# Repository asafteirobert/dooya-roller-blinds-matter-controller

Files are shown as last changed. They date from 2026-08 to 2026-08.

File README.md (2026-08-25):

# Roller Blinds Matter Controller

A Matter over Wi-Fi device for controlling generic Dooya wireless roller blinds. Compatible with blinds that use the Dooya non-rolling code protocol over 433MHz. They are sold under many generic brands such as Smart Home, glb, MOSEL, and HEICKO, have model names such as DM35R, and use remotes such as DC104, DC105, DC169.

## Features
- Position control based on timing. The device times the up/down/stop commands based on total travel time to move the blind to the desired position. At the top and bottom position the stop command is not sent and any accumulated error is fixed.
- Ability to add multiple blinds to the same device.
- Configure the number of blinds and blind parameters (rise time, lower time, channel and remote code) through Matter using a custom script.
- Device listens to the physical remote for commands to keep the internal and Matter state in sync regardless of whether the blinds are controlled through Matter or through the physical remote.

## Hardware
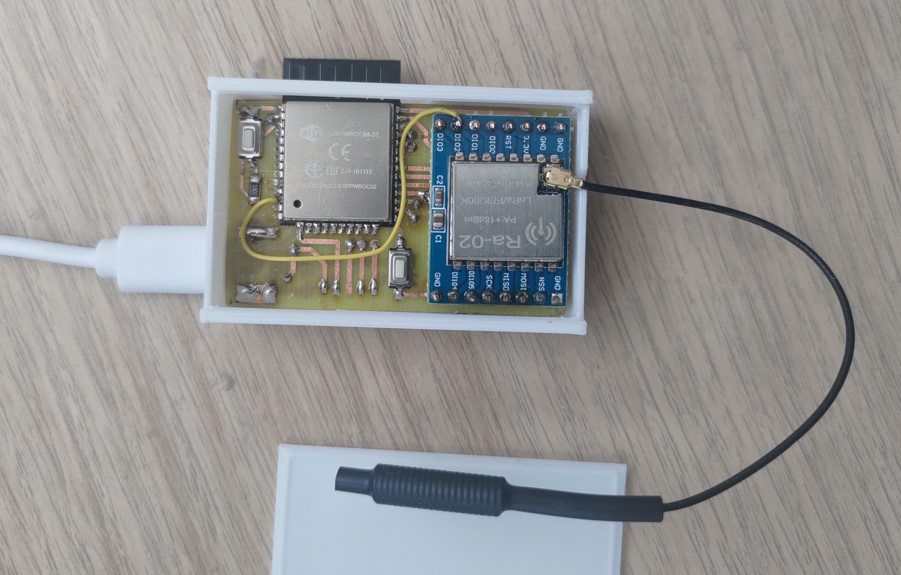
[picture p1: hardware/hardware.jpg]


ESP32 (ESP-WROOM-32) connected to an SX1278 RF module. The RF module both transmits the OOK commands the wireless remote would send and receives commands from the physical remote, so the device can stay in sync regardless of how the blind was last controlled.

See [hardware](hardware/).

## Commissioning

Use the scripts in `mfg-tool-scripts/` to generate and flash per-device commissioning data:

```bash
./0_clean.sh      # remove previous outputs
./1_generate.sh   # generate new commissioning data
./2_flash.sh      # flash to device (default port: /dev/ttyUSB0)
```

Override the port: `PORT=/dev/ttyACM0 ./2_flash.sh`.

Commissioning QR code (alongside the manual code) can be found in `mfg-tool-scripts/out/fff1_8003/<hash>/<hash>-qrcode.png`.

## Obtaining your unique remote ID code

Enable debug logging by uncommenting and commenting out the relevant lines in `sdkconfig.defaults` and look for `Received remote command X from remote 0xXXXXX channel X`. Use the script in `tools/write-blind-config` to write the remote ID and channel to the correct Matter endpoint (see below).

Alternatively, you can use an RTL-SDR dongle and the [rtl_433 tool](https://github.com/merbanan/rtl_433) tool with the `dooya_curtain.conf` file in this repository: `rtl_433.exe -c hardware/dooya_curtain.conf`.

## Configuring blinds (tools/write-blind-config)

`matter-server` and `@matter/nodejs-shell` can't write the device's custom manufacturer clusters (`BlindConfig` / `SystemConfig`), so this standalone matter.js script commissions itself as a second controller on the device (Matter supports multiple admins, so this doesn't disturb an existing Home Assistant pairing) and writes the attributes directly.

**Setup** (from `tools/write-blind-config/`):
```bash
npm install
```

**Usage:**

Comission the device in this script using the pairing code, then set the number of blinds, then configure each blind.
```bash
node write-blind-config.mjs [--pairing-code <code>] [--endpoint <n>] [--lower <ms>] [--rise <ms>] [--channel <n>] [--remote-id <hex-or-decimal>] [--num-blinds <n>]
```
- `--pairing-code`. The script needs to commission itself onto the device, which requires a pairing code from Home Assistant (device page → "..." menu → "Share device"). After that, the script's local storage remembers the pairing, so `--pairing-code` can be omitted on later runs.
- `--lower` sets the time in milliseconds it takes for the blind to go from fully open to fully closed.
- `--rise` sets the time in milliseconds it takes for the blind to go from fully closed to fully open.
- `--remote-id` sets the unique remote pairing code
- `--num-blinds` always targets endpoint 0 and reboots the device ~2s after the write to rebuild its set of blind endpoints. If combined with per-blind flags, those are written first.
- Any subset of `--lower`/`--rise`/`--channel`/`--remote-id`/`--num-blinds` is fine, as long as at least one is given.
- `--endpoint` selects which blind's config the first four flags target (default `1`). I can be found in the Matter Server web ui in Home Assistant. Or from the device serial log: `Window covering N created with endpoint_id X`.

Example — configure blind on endpoint 2 with a 12s lower time, 13s rise time, channel 2, remote ID `0x123456`:
```bash
node write-blind-config.mjs --endpoint 2 --lower 12000 --rise 13000 --channel 2 --remote-id 0x123456
```
## AI Disclaimer
This project was coded with heavy use of Claude Code

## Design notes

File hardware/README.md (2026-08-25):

# Hardware

- **[Schematic](Schematic/)** — Schematic, PCB and EasyEDA project. The PCB was manufactured at home with only the top side, so some connections use wires. This is why some of the routing, large vias and DRC rules look strange.
- **[3d print](3d%20print/)** — 3D model of the case.

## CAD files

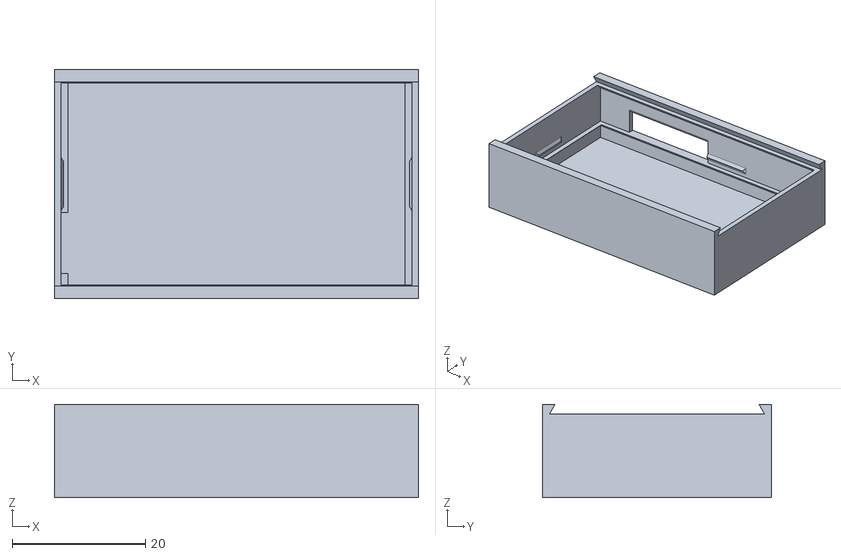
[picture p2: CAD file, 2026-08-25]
hardware/3d print/Roller blinds Case.stl
54.7 x 34.4 x 14.1

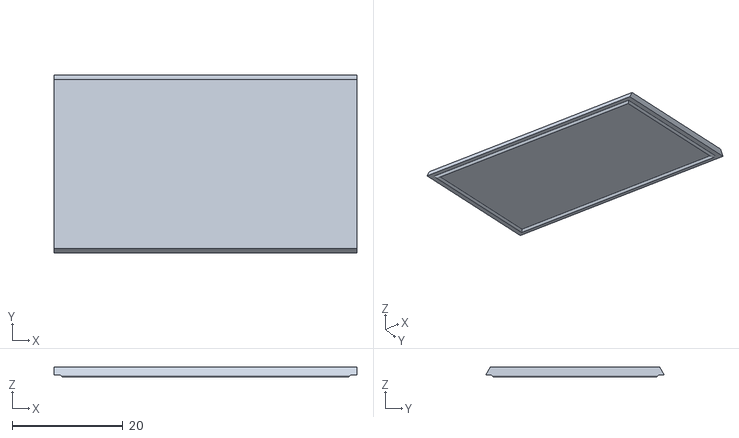
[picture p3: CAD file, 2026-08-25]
hardware/3d print/Roller blinds Case Lid.stl
54.7 x 32.2 x 1.80

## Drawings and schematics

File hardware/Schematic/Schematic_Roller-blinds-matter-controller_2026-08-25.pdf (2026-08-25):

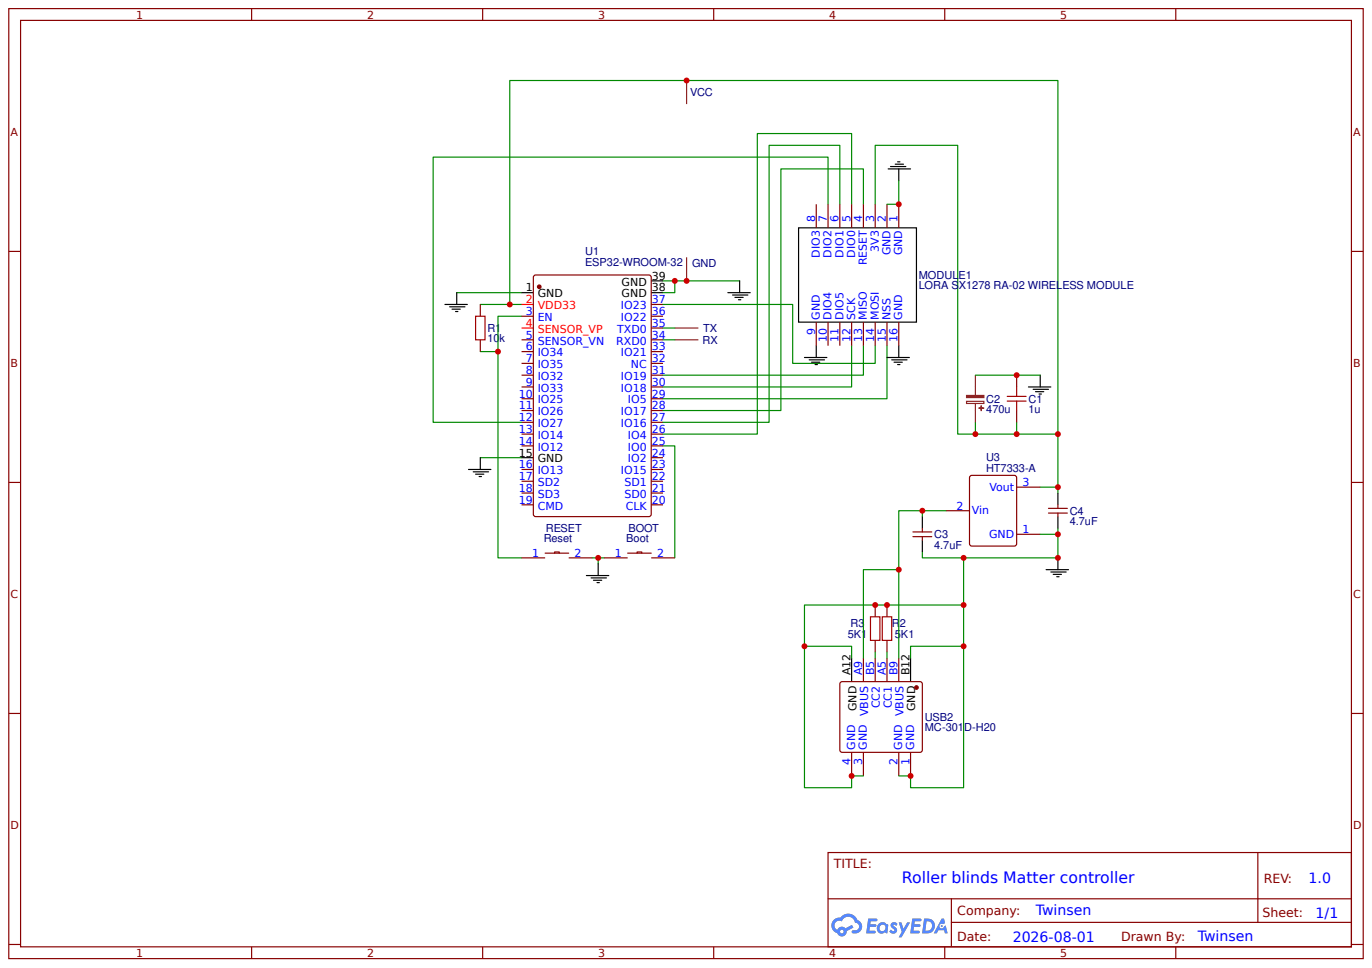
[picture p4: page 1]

GND 1 GND 2 3V3 3 RESET 4 DIO0 5 DIO1 6 DIO2 7 DIO3 8 GND 9 DIO4 10 DIO5 11 SCK 12 MISO 13 MOSI 14 NSS 15 GND 16

MODULE1
LORA SX1278 RA-02 WIRELESS MODULE

CLK 20 CMD 19 SD3 18 SD2 17 IO13 16 GND 15 IO12 14 IO14 13 IO27 12 IO26 11 IO25 10 IO33 9 IO32 8 IO35 7 IO34 6 SENSOR_VN 5 SENSOR_VP 4 EN 3 VDD33 2 GND 1

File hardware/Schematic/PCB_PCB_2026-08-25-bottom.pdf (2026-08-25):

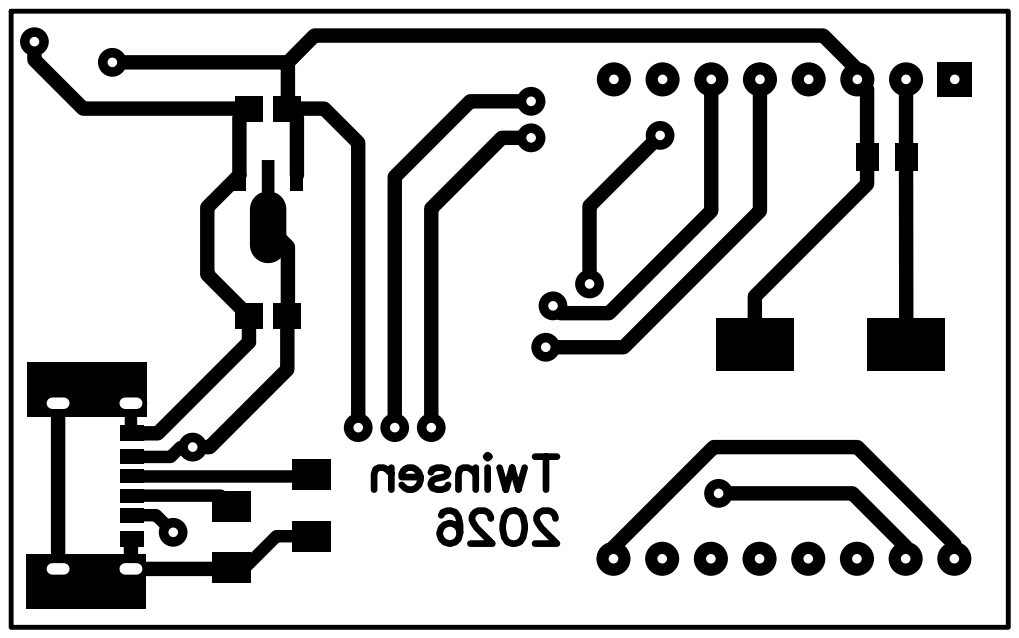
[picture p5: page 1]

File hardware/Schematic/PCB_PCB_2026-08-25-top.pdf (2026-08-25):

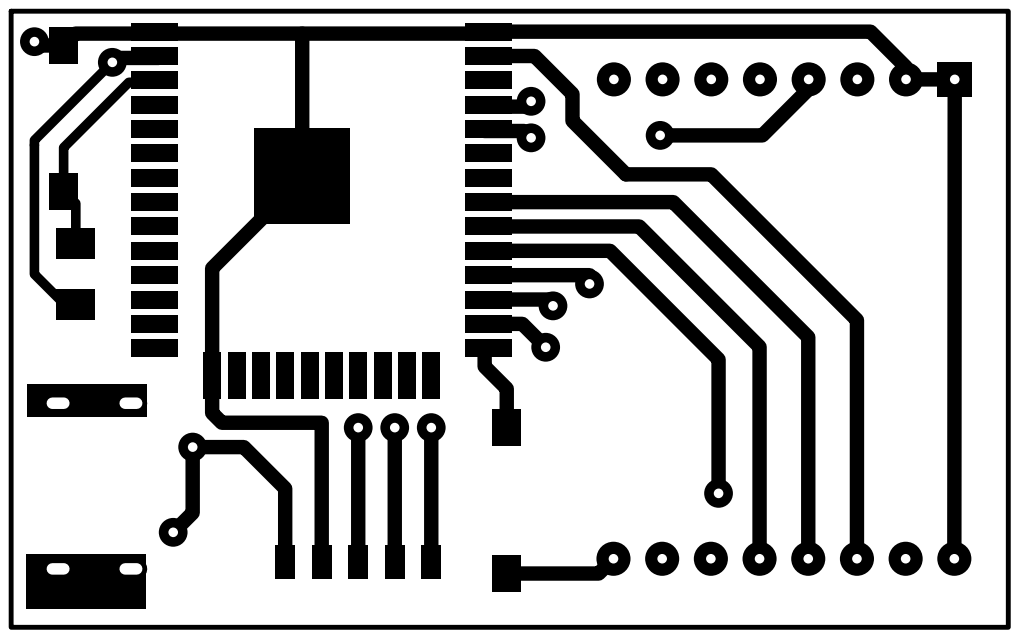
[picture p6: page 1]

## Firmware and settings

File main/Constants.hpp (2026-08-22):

#pragma once
#include <cstdint>

#include "driver/gpio.h"

/** Factory-reset button (active-LOW, internal pull-up) */
#define BOARD_BUTTON_GPIO GPIO_NUM_0

#define SX1278_NSS_GPIO GPIO_NUM_5
#define SX1278_RESET_GPIO GPIO_NUM_17
#define SX1278_DIO0_GPIO GPIO_NUM_4
#define SX1278_DIO1_GPIO GPIO_NUM_16
// Raw OOK "Data" output (continuous mode), used to receive commands sent by the physical remote.
// Only meaningful while the chip is in receive mode; see SX1278Driver's RX decode state machine.
#define SX1278_DIO2_GPIO GPIO_NUM_27

// Debug-only outputs
#define SX1278_RX_DEBUG_1_GPIO GPIO_NUM_25 
#define SX1278_RX_DEBUG_2_GPIO GPIO_NUM_26

// Maximum number of blinds this firmware can be configured to control. Shared between app_main
// (which sizes its per-blind endpoint/controller arrays with it) and RadioController (which
// sizes its remote-command routing table with it), so the two stay in sync.
constexpr uint8_t MAX_BLINDS = 8;

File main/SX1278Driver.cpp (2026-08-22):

#include "SX1278Driver.hpp"
#include "Constants.hpp"

#include <algorithm>
#include <cinttypes>
#include <utility>

#include <driver/gpio.h>
#include <driver/mcpwm_cap.h>
#include <driver/pulse_cnt.h>
#include <driver/spi_master.h>
#include <esp_attr.h>
#include <esp_log.h>
#include <esp_rom_sys.h>
#include <esp_timer.h>
#include <freertos/FreeRTOS.h>
#include <freertos/semphr.h>
#include <freertos/task.h>

namespace
{
// --- OOK/PWM timing
constexpr uint32_t SYNC_US = 4600;
constexpr uint32_t SHORT_US = 350; // logical bit 0
constexpr uint32_t LONG_US = 700;  // logical bit 1
constexpr uint32_t RESET_US = 7500; // silence between repeated frames

// On-air sample period. Must evenly divide every timing value above (it's the GCD: 50 = 2*5^2).
constexpr uint32_t SAMPLE_US = 50;
static_assert(SYNC_US % SAMPLE_US == 0 && SHORT_US % SAMPLE_US == 0 && LONG_US % SAMPLE_US == 0,
              "SAMPLE_US must evenly divide the pulse widths or the waveform will be built with rounding error");

constexpr uint32_t SYNC_CHIPS = SYNC_US / SAMPLE_US;
constexpr uint32_t SHORT_CHIPS = SHORT_US / SAMPLE_US;
constexpr uint32_t LONG_CHIPS = LONG_US / SAMPLE_US;

constexpr double FXOSC_HZ = 32000000.0;
constexpr double RF_FREQUENCY_HZ = 433915000.0; // Dooya remotes operate in the 433 MHz ISM band
constexpr uint32_t BIT_RATE_BPS = 1000000 / SAMPLE_US; // one on-air bit == one SAMPLE_US chip

constexpr int SPI_CLOCK_HZ = 4 * 1000 * 1000; // conservative for hobby-wired breakout boards

// The FIFO is only 64 bytes deep, so any payload longer than that (ours always is) is streamed in
// while transmitting per the datasheet's "Handling Large Packets" procedure: pre-fill, enable Tx,
// then top up in FIFO_CHUNK bursts whenever FifoLevel (mirrored on DIO1) drops to the threshold.
constexpr size_t FIFO_CAPACITY = 64;
constexpr size_t FIFO_CHUNK = 32;
constexpr uint8_t FIFO_THRESHOLD = FIFO_CAPACITY - FIFO_CHUNK; // leaves exactly one chunk of headroom

constexpr int64_t FIFO_WAIT_TIMEOUT_US = 500000; // generous vs. the ~60-90 ms a real transfer takes

// Deep enough to absorb a burst of UI/Matter-driven commands without send() ever blocking on air time.
constexpr UBaseType_t COMMAND_QUEUE_LENGTH = 16;
constexpr uint32_t SENDER_TASK_STACK_WORDS = 4096;
constexpr UBaseType_t SENDER_TASK_PRIORITY = 5;

// Minimum gap between the end of one queued command and the start of the next
constexpr uint32_t COMMAND_GAP_MS = 200;

// Deep enough to absorb a burst of repeated button presses without the ISR ever blocking/dropping.
constexpr UBaseType_t RX_FRAME_QUEUE_LENGTH = 8;
constexpr uint32_t RECEIVER_TASK_STACK_WORDS = 4096;
constexpr UBaseType_t RECEIVER_TASK_PRIORITY = 5;

// dio2SetupTask() runs the MCPWM/PCNT setup from core 1 (see there) so their interrupts bind away
// from WiFi/BLE's dispatch, which is pinned to core 0.
constexpr uint32_t DIO2_SETUP_TASK_STACK_WORDS = 3072;
constexpr UBaseType_t DIO2_SETUP_TASK_PRIORITY = 5;
constexpr BaseType_t DIO2_SETUP_CORE = 1;

struct Dio2SetupContext
{
    SX1278Driver* driver;
    SemaphoreHandle_t doneSemaphore;
};

// ESP32's PCNT counter register is a signed 16-bit field.
constexpr int PCNT_LOW_LIMIT = -32768;
constexpr int PCNT_HIGH_LIMIT = 32767;
// handleReceivedEdge() resets rxIsrEdgeCount (and the PCNT counter) back to 0 once it reaches this,
// well below the hardware ceiling above -- see there. Any value comfortably below the ceiling works.
constexpr int PCNT_RESET_THRESHOLD = 20000;

// --- OOK/PWM RX decode tolerances, mirroring buildWaveform()'s encoding in reverse. Only each
// HIGH ("mark") run's duration is decoded -- LONG_US means 1, SHORT_US means 0 -- since the
// complementary space carries no extra information. Each band is separated from its neighbours by
// a dead zone: a duration landing in a gap aborts the in-progress frame (see handleReceivedEdge)
// instead of being forced into the nearest band, so jitter can't silently flip a bit into a
// plausible-but-wrong frame. A dropped frame is harmless -- the remote repeats every press.
constexpr int64_t RX_SHORT_MIN_US = 180;
constexpr int64_t RX_SHORT_MAX_US = 460; // SHORT_US(350) + ~31%
constexpr int64_t RX_LONG_MIN_US = 590;  // LONG_US(700) - ~16% -- 130us dead zone vs RX_SHORT_MAX_US
constexpr int64_t RX_LONG_MAX_US = 1000; // LONG_US(700) + ~43%, comfortably below RX_SYNC_MIN_US
constexpr int64_t RX_SYNC_MIN_US = 2800; // SYNC_US(4600) - ~39%, comfortably above RX_LONG_MAX_US
constexpr int64_t RX_SYNC_MAX_US = 6200; // SYNC_US(4600) + ~35%
constexpr uint8_t RX_FRAME_BITS = 40;

// Below RX_SHORT_MIN_US by a wide margin, so a run this brief is always an RF/electrical glitch,
// never a real mark or space -- see rxPendingValid.
constexpr int64_t RX_NOISE_MAX_US = 50;

// The sync mark is always followed by a fixed 2*LONG_US (1400us) low gap before the first bit's
// mark (see buildWaveform()). Requiring that gap to also match before committing to "in frame"
// needs a noise glitch to land in *two* independent windows to be mistaken for a real frame.
constexpr int64_t RX_POST_SYNC_GAP_MIN_US = 1050;
constexpr int64_t RX_POST_SYNC_GAP_MAX_US = 1850;

// --- SX1278 FSK/OOK register map (see RFM9x/SX1278 datasheet section 6.2) ---
constexpr uint8_t REG_FIFO = 0x00;
constexpr uint8_t REG_OP_MODE = 0x01;
constexpr uint8_t REG_BITRATE_MSB = 0x02;
constexpr uint8_t REG_BITRATE_LSB = 0x03;
constexpr uint8_t REG_FRF_MSB = 0x06;
constexpr uint8_t REG_FRF_MID = 0x07;
constexpr uint8_t REG_FRF_LSB = 0x08;
constexpr uint8_t REG_PA_CONFIG = 0x09;
constexpr uint8_t REG_PA_RAMP = 0x0A;
constexpr uint8_t REG_RX_CONFIG = 0x0D;
constexpr uint8_t REG_RX_BW = 0x12;
constexpr uint8_t REG_OOK_PEAK = 0x14;
constexpr uint8_t REG_OOK_FIX = 0x15;
constexpr uint8_t REG_RSSI_VALUE = 0x11;
constexpr uint8_t REG_PREAMBLE_MSB = 0x25;
constexpr uint8_t REG_PREAMBLE_LSB = 0x26;
constexpr uint8_t REG_SYNC_CONFIG = 0x27;
constexpr uint8_t REG_PACKET_CONFIG1 = 0x30;
constexpr uint8_t REG_PACKET_CONFIG2 = 0x31;
constexpr uint8_t REG_PAYLOAD_LENGTH = 0x32;
constexpr uint8_t REG_FIFO_THRESH = 0x35;
constexpr uint8_t REG_VERSION = 0x42;

constexpr uint8_t SPI_WRITE_BIT = 0x80;

// RegOpMode: LongRangeMode=0 (FSK/OOK) | ModulationType=01 (OOK) | LowFrequencyModeOn=1 (<525MHz)
constexpr uint8_t MODULATION_OOK_LF = 0x28;
constexpr uint8_t OPMODE_SLEEP = MODULATION_OOK_LF | 0x00;
constexpr uint8_t OPMODE_STANDBY = MODULATION_OOK_LF | 0x01;
constexpr uint8_t OPMODE_TX = MODULATION_OOK_LF | 0x03;
constexpr uint8_t OPMODE_RX_CONTINUOUS = MODULATION_OOK_LF | 0x05;

// RegPacketConfig2 DataMode: Packet for Tx, Continuous for Rx (our protocol has no SX1278-framable
// preamble/sync word, so DIO2 is read as a raw envelope and decoded in software instead).
constexpr uint8_t PACKET_CONFIG2_DATA_MODE_PACKET = 0x40;
constexpr uint8_t PACKET_CONFIG2_DATA_MODE_CONTINUOUS = 0x00;
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

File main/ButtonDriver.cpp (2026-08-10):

#include "ButtonDriver.hpp"
#include "Constants.hpp"

#include <esp_err.h>
#include <esp_log.h>
#include <esp_matter.h>

void ButtonDriver::init()
{
    const button_config_t btn_cfg = 
    {
        .long_press_time  = 5000,   // 5 s - factory reset
        .short_press_time = 50,
    };
    const button_gpio_config_t btn_gpio_cfg = 
    {
        .gpio_num = BOARD_BUTTON_GPIO,
        .active_level = 0,
    };

    if (iot_button_new_gpio_device(&btn_cfg, &btn_gpio_cfg, &this->handle) != ESP_OK) 
    {
        ESP_LOGE(TAG, "Failed to create button device");
        return;
    }

    esp_err_t err = ESP_OK;
    err |= iot_button_register_cb(this->handle, BUTTON_SINGLE_CLICK, NULL, buttonClickCallback, this);
    err |= iot_button_register_cb(this->handle, BUTTON_LONG_PRESS_HOLD, NULL, buttonLongPressHoldCallback, this);
    err |= iot_button_register_cb(this->handle, BUTTON_PRESS_UP, NULL, buttonPressUpCallback, this);
    if (err != ESP_OK)
    {
        ESP_LOGE(TAG, "Failed to set button callbacks");
        return;
    }

    ESP_LOGI(TAG, "Button initialised on GPIO %d", BOARD_BUTTON_GPIO);
    return;
}

void ButtonDriver::buttonClickCallback(void *handle, void *userData)
{
}

void ButtonDriver::buttonLongPressHoldCallback(void *handle, void *userData)
{
    ButtonDriver* thisInstance = (ButtonDriver*)userData;
    if (!thisInstance->performFactoryReset)
    {
        ESP_LOGI(TAG, "Factory reset triggered. Release the button to start factory reset.");
        thisInstance->performFactoryReset = true;
    }
}

void ButtonDriver::buttonPressUpCallback(void *handle, void *userData)
{
    ButtonDriver* thisInstance = (ButtonDriver*)userData;
    if (thisInstance->performFactoryReset)
    {
        ESP_LOGI(TAG, "Starting factory reset");
        esp_matter::factory_reset();
        thisInstance->performFactoryReset = false;
    }
}

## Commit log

2026-08-06 Basic controller driver ownership and lifetime
2026-08-08 SX1276Driver no longer blocks
    [SX1276Driver.cpp]
2026-08-20 Drop glitches and add logging
    [SX1278Driver.cpp]
2026-08-22 Fix disabling RX on every repeat
    [SX1278Driver.cpp]
2026-08-25 README, schematic, 3d files
    [Roller blinds Case Lid.stl, Roller blinds Case.stl]
